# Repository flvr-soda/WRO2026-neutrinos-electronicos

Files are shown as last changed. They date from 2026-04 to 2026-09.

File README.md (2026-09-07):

# Neutrinos Electrónicos WRO 2026 - Terreneitor

## Table of Contents

- [Project Overview](#project-overview)
- [Team Introduction](#team-introduction)
- [The Robot: Terreneitor](#the-robot-terreneitor)
- [System Architecture](#system-architecture)
- [Hardware Specifications](#hardware-specifications)
- [Software Architecture](#software-architecture)
  - [Programming Languages](#programming-languages)
  - [Python Libraries](#python-libraries)
  - [Flowcharts](#flowcharts)
  - [Directory Structure](#directory-structure)
- [Algorithmic Logic](#algorithmic-logic)
  - [Finite State Machine (FSM)](#finite-state-machine-fsm)
  - [Computer Vision Processing](#computer-vision-processing)
  - [LiDAR-Based Parking](#lidar-based-parking)
  - [Serial Communication Protocol](#serial-communication-protocol)
- [Emergency Navigation System](#emergency-navigation-system)
- [Module Descriptions](#module-descriptions)
- [Installation and Setup](#installation-and-setup)
- [Configuration](#configuration)
- [Usage Instructions](#usage-instructions)
- [Component List](#component-list)
- [Robot Images](#robot-images)
- [Practice Videos](#practice-videos)
- [Development Milestones](#development-milestones)

---

## Project Overview

**Terreneitor** is an autonomous vehicle designed for the World Robot Olympiad (WRO) 2026 Future Engineers competition. The robot implements a hybrid computing architecture combining a **Raspberry Pi 4** as the high-level perception and decision unit and an **Arduino UNO** as the real-time hardware controller. This design guarantees sophisticated decision-making alongside deterministic, low-latency motor control.

**Key Design Principles:**
- **Hybrid Centralized Architecture:** Single Raspberry Pi 4 as master node with Arduino UNO as dedicated hardware controller to eliminate latency issues.
- **Isolated Control Loop:** PID-based motor control with encoder feedback running directly on the Arduino for immediate, smooth velocity regulation.
- **Configuration-Driven Logic:** Main competition parameters decoupled from source code via centralized `config.py` for rapid adjustments.
- **Modular Software Design:** Event-based Finite State Machine (FSM) on Raspberry Pi enabling independent development and validation of each race phase.
- **Dual-Track Reliability:** Complete primary vision-based navigation system alongside a lightweight, reactive **Safety System** (`code/safety_sys`).

---

## Team Introduction

<p align="center">
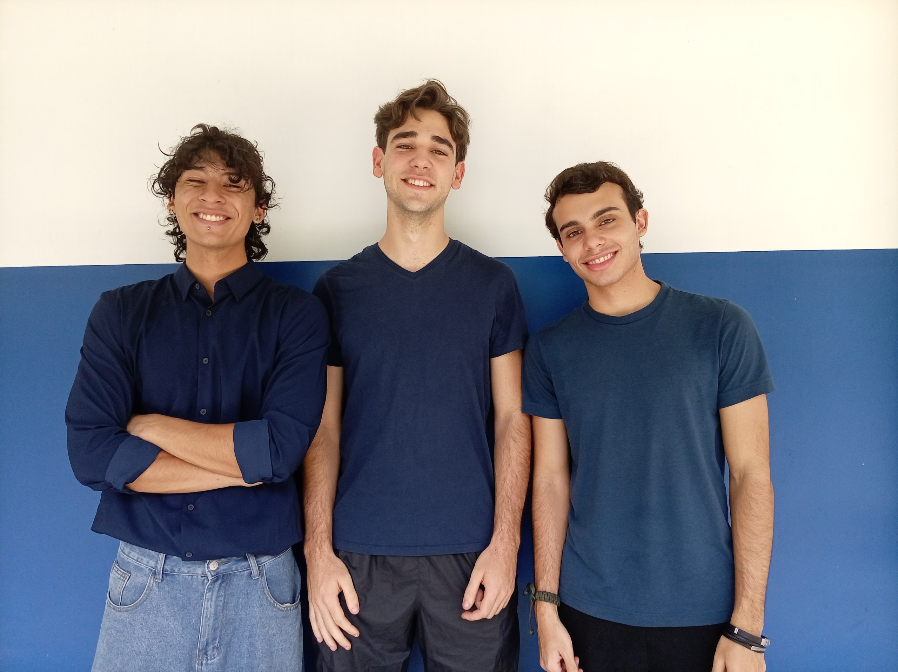
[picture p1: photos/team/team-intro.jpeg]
Team Photo
  
</p>

| Name | Role |
|---|---|
| **Ismael Armada** | Software Architecture & Control |
| **Sebastián Vera** | Mechanics & Chassis Design |
| **Andrés Lugo** | Electronics & Power Systems |
| **Milagro Rojas** | Coach |

- **Ismael Armada:** I am 20 years old, in my 4th semester of my Computer Science major. I learned about WRO thanks to a mutual friend I share with our team's coach. With this competition, I simply aim to challenge myself as a programmer by diving headfirst, for the very first time, into the development of a robotics project.
- **Sebastián Vera:** I am 18 years old and a Mechanical Engineering student, currently in my 3rd semester. I discovered WRO through my high school, as we were able to represent it during our senior year. I loved that experience, and it introduced me to this amazing world of robotics—how fun and challenging it really is! I hope to have the opportunity to represent both my team and my country in such an incredible competition.
- **Andrés Lugo:** I am 19 years old and an Electrical Engineering student, currently taking 2nd-semester courses in Mechanical Engineering. I got to know WRO by competing alongside Sebastián for the first time in our senior year of high school. I didn't have much knowledge back then, but it was my gateway into this world.

---

## The Robot: Terreneitor

Every project needs an identity, and ours was born out of a shared childhood memory. During one of our first team meetings, a conversation about remote-controlled cars revealed that every single member of our team had owned a "Terreneitor" toy car growing up. That shared memory inspired the name of our autonomous vehicle.

---

## System Architecture

The robot employs a dual-processor architecture optimized for high-level perception and real-time execution:

```
+-------------------------------------------------------------+
|                      RASPBERRY PI 4                         |
|  - Computer Vision (OpenCV / CSI Camera)                    |
|  - TF-Luna LiDAR Reader & SG90 Servo Control                |
|  - Finite State Machine (INICIO, NAVEGACION, ESTACIONAR)    |
|  - PID Steering & Speed Calculation                         |
|  - Rule Enforcement & Lap Counter                           |
+------------------------------+------------------------------+
                               | USB Serial (115200 baud)
                               | Command: V:<vel>;A:<ang>\n
                               | Telemetry: T:Z:<z>;A:<a>;U:<u>\n
+------------------------------v------------------------------+
|                       ARDUINO UNO                           |
|  - Non-blocking Command Parser                              |
|  - BTS7960 H-Bridge DC Motor PWM Drive                      |
|  - MG996R Steering Servo Control (40° - 140°)               |
|  - 100-line Quadrature Optical Encoder Interrupts           |
|  - HC-SR04 Rear Ultrasonic Distance Reader                  |
|  - MPU6050 6-DOF IMU Yaw Angle Integration                  |
+-------------------------------------------------------------+
```

---

## Hardware Specifications

### Main Processing Units
- **SBC:** Raspberry Pi 4 Model B (4GB RAM)
- **MCU:** Arduino UNO R3

### Power Architecture
- Independent high-capacity battery pack for traction motors
- Dedicated power supply for Raspberry Pi 4 and Arduino
- Voltage regulator: **XL4015** step-down buck converter (high-current stabilization)
- 5V active cooling fan for Raspberry Pi 4
- Two distinct switches: Main master power and physical start button (GPIO 23 / Pin 16)

### Sensors
- **Camera:** OV5647 5MP with 120° wide-angle field of view (CSI ribbon interface)
- **Front LiDAR:** TF-Luna ToF distance sensor mounted on SG90 panning servo
- **Rear Distance:** HC-SR04 ultrasonic sensor (connected to Arduino)
- **IMU:** MPU6050 6-DOF accelerometer and gyroscope (I2C)
- **Speed Sensor:** 100-line optical quadrature encoder on main transmission

### Actuators
- **Motor Driver:** BTS7960 43A High-Power H-Bridge
- **Traction Motor:** High-torque DC motor
- **Steering Servo:** MG996R metal-gear 180° servo motor
- **LiDAR Panning Servo:** SG90 micro servo

---

## Software Architecture

### Programming Languages
- **Python 3:** Raspberry Pi high-level logic, state machine, vision, and emergency modules.
- **C++:** Arduino firmware for real-time motor drive and sensor polling.

### Python Libraries
- `opencv-python`: Real-time color detection, ROI extraction, and morphological filtering.
- `pyserial`: Direct non-blocking serial communication between Pi and Arduino.
- `gpiozero`: Hardware interface for physical start button (WRO Rule 9.11) and servos.
- `numpy`: Numerical processing for vision masks and arrays.

### Flowcharts

#### 1. Raspberry Pi Perception & Decision-Making Flow

#### 2. Arduino UNO Real-Time Control Flow

#### 3. Integrated Dual-Node System & Inter-Board Communication

### Directory Structure

```
WRO2026-neutrinos-electronicos/
├── README.md                         # Main project documentation
├── LICENSE                           # Project license
├── .gitignore                        # Git exclusion rules
│
├── code/                             # Source code directory
│   ├── env/                          # Shared Python virtual environment
│   ├── requirements.txt               # Shared Python package dependencies
│   │
│   ├── scripts/                       # Execution and setup scripts
│   │   ├── start.sh                   # Parametrized launcher (robot|safety)
│   │   └── setup_services.sh          # Systemd service installation script
│   │
│   ├── services/                      # Systemd service files
│   │   ├── wro-robot.service          # Primary system service
│   │   └── wro-safety.service         # Alternative system service
│   │
│   ├── main_sys/                      # Primary Navigation System
│   │   ├── src/                        # Core modules
│   │   │   ├── main.py                 # Main entrypoint and FSM orchestrator
│   │   │   ├── config.py               # Direct configuration (no YAML)
│   │   │   ├── estados.py              # Consolidated FSM + states
│   │   │   ├── comms.py                # Arduino + LiDAR serial drivers
│   │   │   ├── vision.py               # Asynchronous HSV color detection
│   │   │   └── hardware.py            # Hardware interfaces for testing
│   │   └── tests/                      # Standalone diagnostic tests
│   │       ├── test_camara.py          # Camera headless & GUI diagnostic
│   │       ├── test_lidar.py           # LiDAR & servo angle test
│   │       ├── test_ultrasonico.py      # Ultrasonic reading test
│   │       └── test_completo.py       # Full sensor integration test
│   │
│   ├── safety_sys/                     # Alternative Navigation System
│   │   └── main.py                     # Dynamic mode reactive racer
│   │
│   └── arduino/                        # Arduino C++ Firmware
│       └── firmware_terreneitor.ino   # Monolithic firmware (motors, sensors, comms)
│
├── elec/                             # Electrical schematics and diagrams
├── mech/                             # 3D models and CAD files
├── photos/                           # Team and vehicle photographic documentation
└── videos/                           # Practice run videos
```

---

## Configuration

The system uses direct Python configuration in `main_sys/src/config.py` instead of YAML files. All competition parameters can be adjusted directly in the code:

- **Velocities:** Motor PWM values and target speeds for PID control
- **Servo Angles:** Steering angles for different navigation states
- **HSV Color Ranges:** Detection thresholds for red, green, and magenta
- **Competition Settings:** Lap limits, time limits, and challenge modes
- **Hardware Configuration:** GPIO pins and serial port settings
- **Vision Parameters:** Camera resolution and optical flow calibration
- **LiDAR Settings:** Servo angles and distance thresholds
- **Vehicle Dimensions:** Physical dimensions for parking calculations

The Safety System uses hardcoded constants in `safety_sys/main.py` for simplicity and reliability.

---

## Algorithmic Logic

### Finite State Machine (FSM)

The primary software on the Raspberry Pi uses an event-driven Finite State Machine (`code/raspberry_pi/estados/fsm.py`):

1. **`EstadoInicio` (Standby & Ready):**
   - Initializes sensor communication and hardware drivers.
   - Waits in standby mode until the physical start button (`GPIO 23`) is pressed (WRO Rule 9.11).
   - Transitions to `EstadoNavegacion`.

2. **`EstadoNavegacion` (Race Execution):**
   - Continuously receives non-blocking HSV vision detections (obstacle centroid, color).
   - Computes proportional steering angles to avoid pillars (Red $\rightarrow$ evade left, Green $\rightarrow$ evade right).
   - Tracks lap completion using accumulated encoder telemetry.
   - Enforces the 3-minute WRO round time limit.
   - Transitions to `EstadoEstacionar` (Obstacle Challenge) or `EstadoFin` (Open Challenge).

3. **`EstadoEstacionar` (Parallel Parking):**
   - Executes an automated 4-phase parking sequence using LiDAR gap detection:
     - **Phase 1 (Scan):** Sweeps LiDAR servo to identify the parking bay gap.
     - **Phase 2 (Approach):** Aligns the vehicle alongside the detected gap.
     - **Phase 3 (Reverse Entry):** Reverses into the space with calculated steering angle.
     - **Phase 4 (Straighten):** Centers vehicle between walls.
   - Transitions to `EstadoFin`.

4. **`EstadoFin` (Safe Shutdown):**
   - Immediately stops traction motor (`V:0`), centers steering (`A:90`), and safely releases all hardware connections.

---

## Safety System

Located in [`code/safety_sys/`](code/safety_sys), this system is a single-file, zero-overhead reactive alternative designed to guarantee full completion of 3 laps under high-stress competition conditions without relying on camera lighting calibration, OpenCV, or configuration files.

### Safety System Features:

**[`main.py`](code/safety_sys/main.py) — Dynamic Mode Reactive Racer:**
- Uses direct serial UART reads from the **TF-Luna LiDAR in a fixed forward position ($90^\circ$)** at 40 Hz.
- Cruises in straight lines (`V:65, A:90`).
- Camera always active for color detection (rojo/verde/morado)
- Upon detecting any color, permanently switches to obstacle avoidance mode
- When frontal obstacle is detected ($\le 50\text{ cm}$), performs reactive evasion
- Detects outer track corners ($\le 75\text{ cm}$) and completes 3 laps reliably.
- Automatically halts after exactly 12 corners (3 laps).

The script strictly follows the **WRO 9.11 Standby $\rightarrow$ Start Button** protocol.

---

## Installation and Setup

### Raspberry Pi Setup

1. **Clone repository:**
   ```bash
   cd /home/pi
   git clone https://github.com/flvr-soda/WRO2026-neutrinos-electronicos.git
   cd WRO2026-neutrinos-electronicos/code
   ```

2. **Create shared Python virtual environment & install dependencies:**
   ```bash
   python3 -m venv env
   source env/bin/activate
   pip install -r requirements.txt
   deactivate
   ```

3. **Install systemd services (automated):**
   ```bash
   cd scripts
   ./setup_services.sh setup           # Configure environment and permissions
   ./setup_services.sh install-robot  # Install primary system service
   ./setup_services.sh install-safety # Install alternative system service
   ```

4. **Install Arduino Firmware:**
   - Open `code/arduino/firmware_terreneitor.ino` in Arduino IDE.
   - Select Board `Arduino Uno` and target serial port.
   - Compile and upload.

---

## Usage Instructions

### Manual Execution

**Using the parametrized script:**
```bash
cd /home/pi/WRO2026-neutrinos-electronicos/code
source env/bin/activate

# Primary system
./scripts/start.sh robot

# Safety system
./scripts/start.sh safety
```

**Direct execution:**
```bash
cd /home/pi/WRO2026-neutrinos-electronicos/code
source env/bin/activate

# Primary system
cd main_sys
python3 src/main.py

# Safety system
cd safety_sys
python3 main.py
```

### Systemd Service Management

The `scripts/setup_services.sh` script provides automated service management:

```bash
cd /home/pi/WRO2026-neutrinos-electronicos/code/scripts

# Setup environment and permissions
./setup_services.sh setup

# Install and enable primary system
./setup_services.sh install-robot

# Switch to safety system
./setup_services.sh switch-safety

# Check service status
./setup_services.sh status robot
./setup_services.sh status safety

# View service logs
./setup_services.sh logs robot
./setup_services.sh logs safety
```

**Manual Service Management:**
```bash
# Enable primary system:
sudo systemctl enable wro-robot.service
sudo systemctl start wro-robot.service

# Enable safety system:
sudo systemctl enable wro-safety.service
sudo systemctl start wro-safety.service

# Check status:
sudo systemctl status wro-robot.service
sudo systemctl status wro-safety.service
```

---

## Component List

| Category | Component | Model / Specs | Purpose |
|:---|:---|:---|:---|
| **Processing** | Single Board Computer | Raspberry Pi 4 Model B (4GB) | Vision, FSM, Navigation, Decision Making |
| **Processing** | Microcontroller | Arduino UNO R3 | Real-time Motor Control, Telemetry |
| **Vision** | Camera Module | OV5647 5MP (120° FOV) | Pillar Color & Position Detection |
| **Distance** | LiDAR Sensor | Benewake TF-Luna (ToF UART) | Corner Detection, Wall Ranging & Parking |
| **Distance** | Ultrasonic Sensor | HC-SR04 | Rear Obstacle Measurement |
| **IMU** | Motion Sensor | MPU6050 6-DOF | Yaw Angle Tracking |
| **Actuator** | Motor Driver | BTS7960 43A H-Bridge | DC Traction Motor Drive |
| **Actuator** | Steering Servo | MG996R Metal Gear (180°) | Front Wheel Steering |
| **Actuator** | LiDAR Servo | SG90 Micro Servo (180°) | LiDAR Panning |
| **Regulation** | Buck Converter | XL4015 Step-Down Module | High-Current Clean Voltage Stabilization |

## License

This project is licensed under the MIT License - see the [LICENSE](LICENSE) file for details.

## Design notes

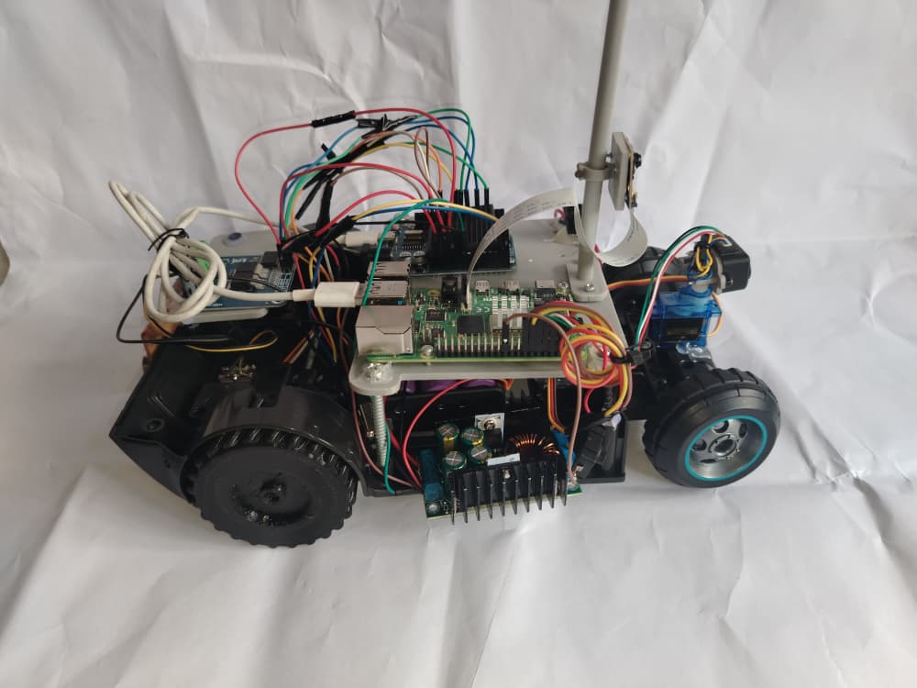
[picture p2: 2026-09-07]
photos/vehicle/izquierda_v3.jpeg

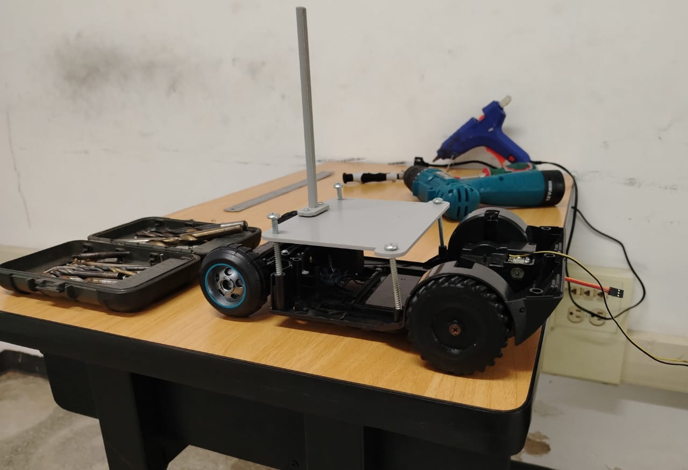
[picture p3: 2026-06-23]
photos/vehicle/terreneitor_v2.jpeg

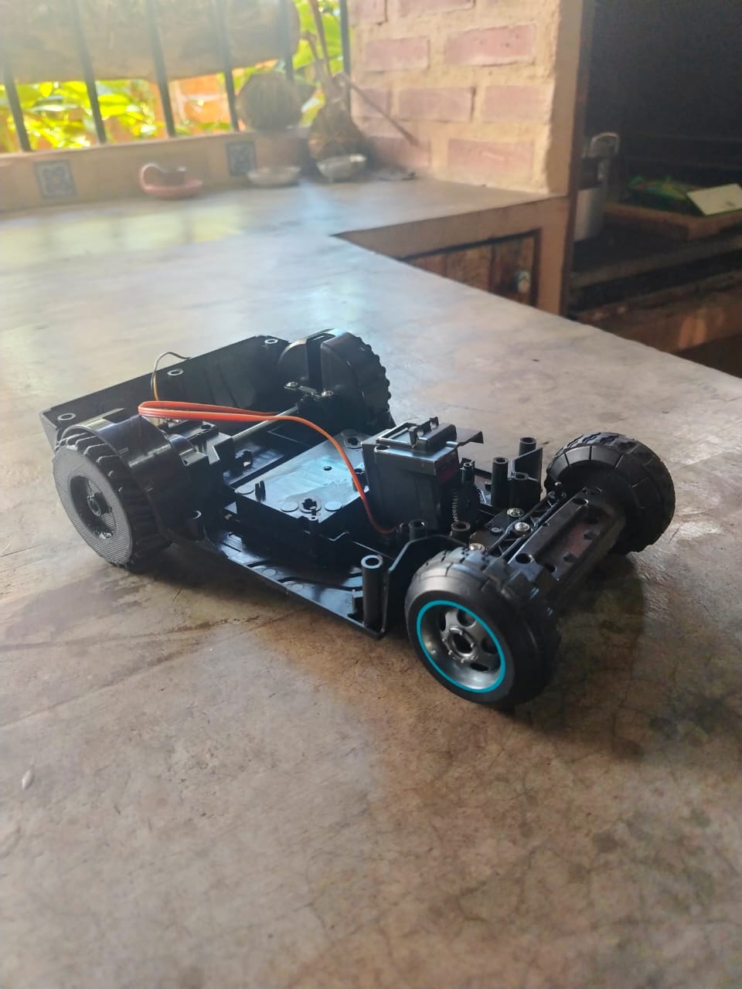
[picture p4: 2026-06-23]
photos/vehicle/terreneitor_v1.jpeg

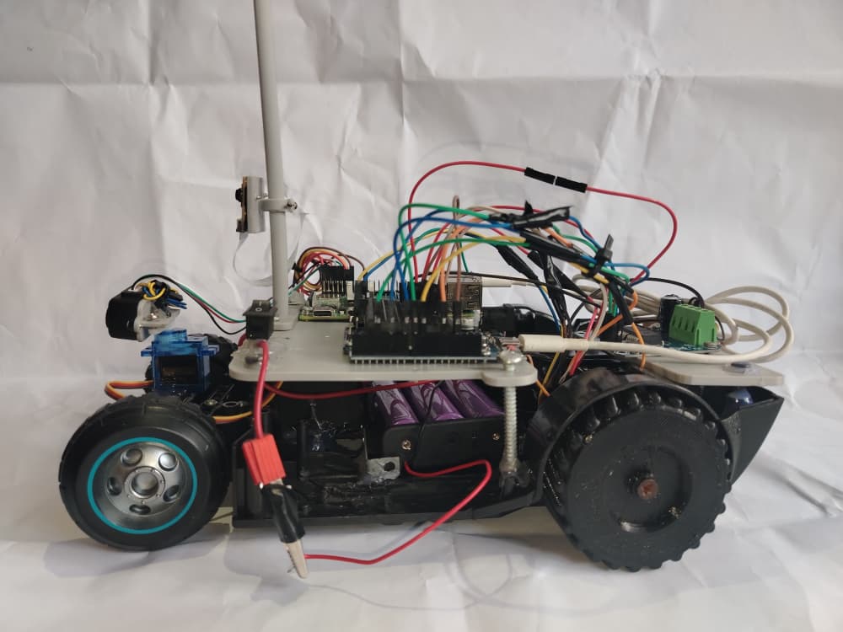
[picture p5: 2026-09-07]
photos/vehicle/derecha_v3.jpeg

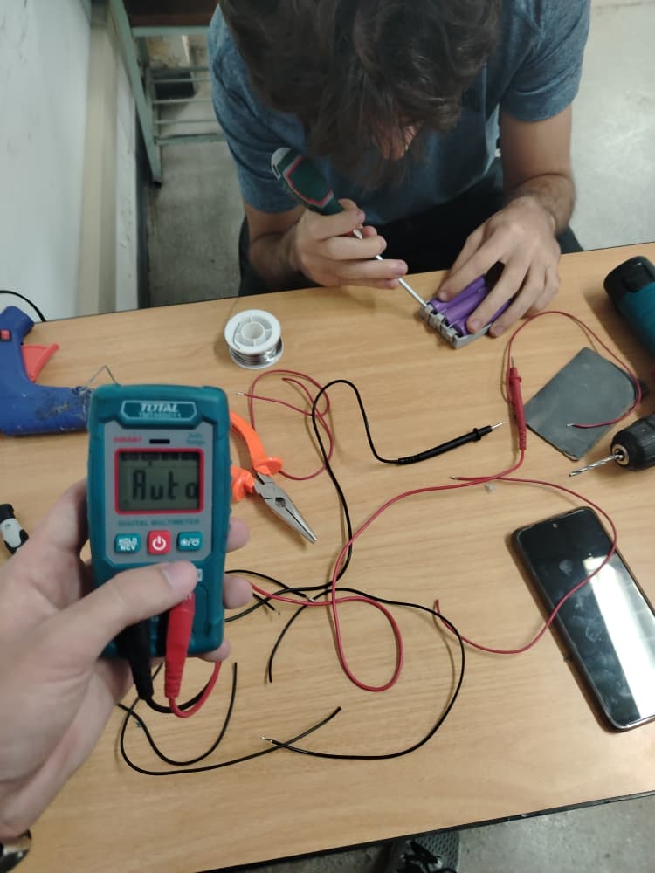
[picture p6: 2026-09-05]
photos/team/Medicion-voltaje-baterias.jpeg

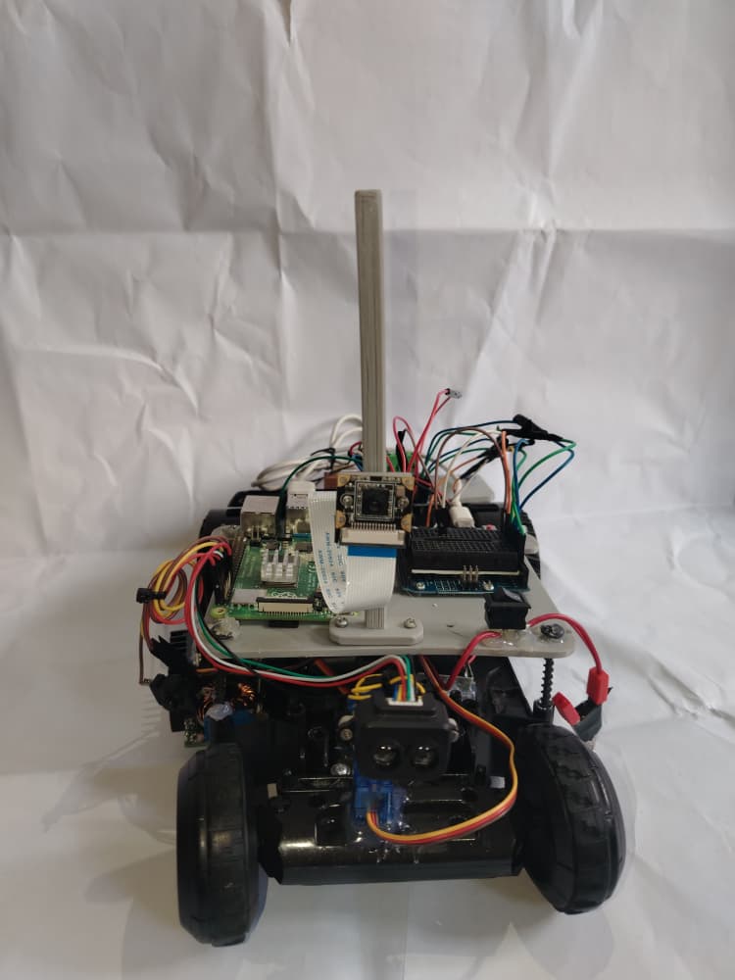
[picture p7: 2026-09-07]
photos/vehicle/frente_v3.jpeg

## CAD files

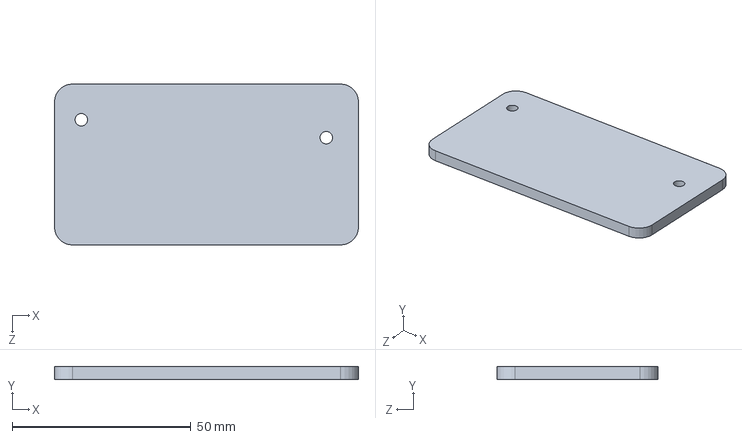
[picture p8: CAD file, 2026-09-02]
mech/3D/Base 2 WRO.SLDPRT
85.0 x 3.50 x 45.0 mm

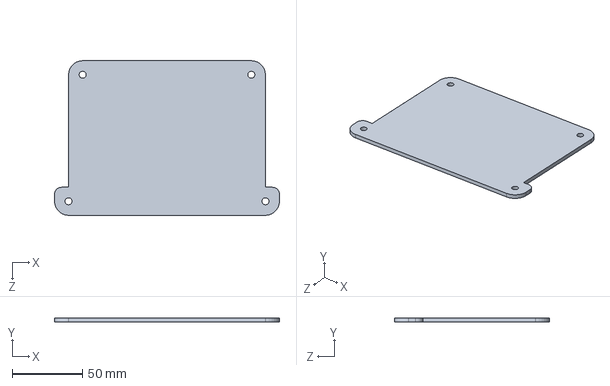
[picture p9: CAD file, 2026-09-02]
mech/3D/Base.SLDPRT
160.0 x 3.00 x 110.0 mm

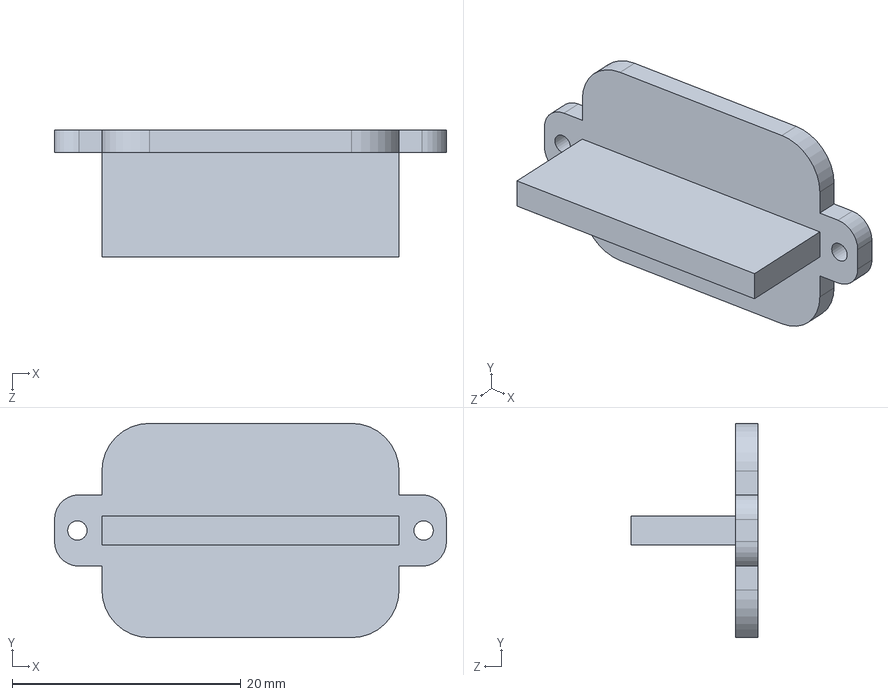
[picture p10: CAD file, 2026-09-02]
mech/3D/Base del Lidar WRO.SLDPRT
34.3 x 18.8 x 11.1 mm

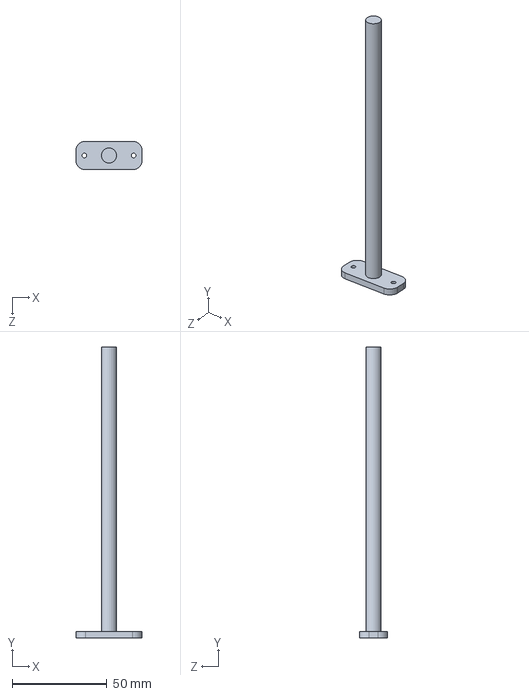
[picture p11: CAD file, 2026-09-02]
mech/3D/Base de la abrazadera WRO.SLDPRT
35.0 x 153.5 x 15.0 mm

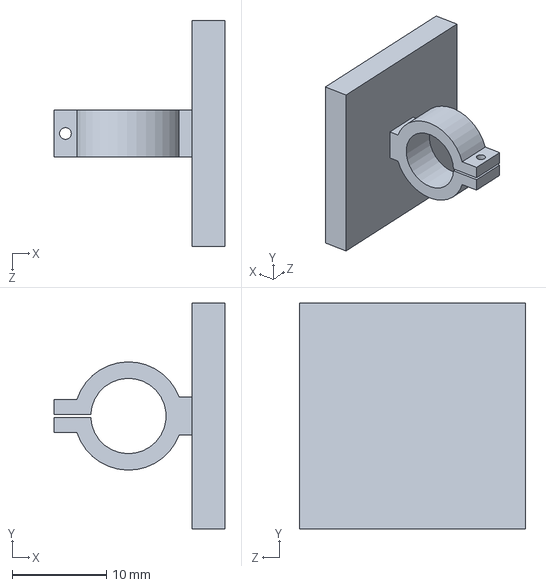
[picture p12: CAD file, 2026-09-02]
mech/3D/Abrazadera WRO.SLDPRT
18.2 x 24.0 x 24.0 mm

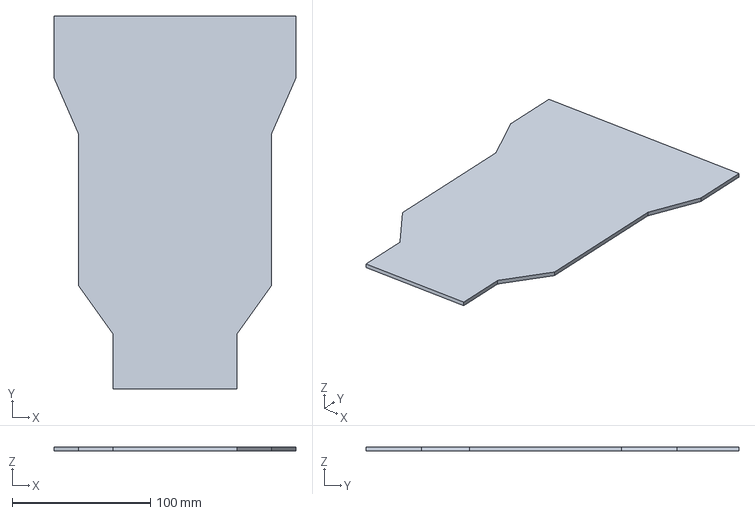
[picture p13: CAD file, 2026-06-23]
mech/3D/Chasis_Dimensiones_Preliminar.FCStd
175.0 x 270.0 x 3.00 mm

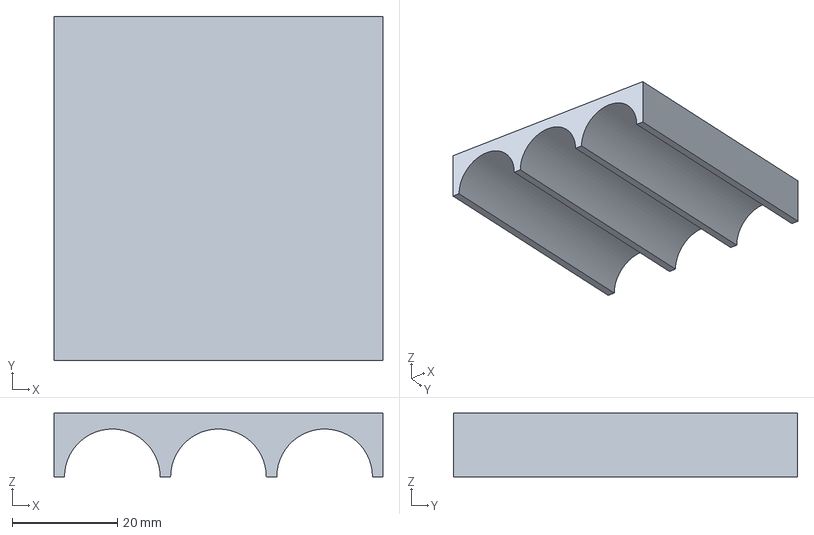
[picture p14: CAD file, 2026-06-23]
mech/3D/Chasis_Soporte_Baterias.FCStd
62.5 x 65.3 x 12.1 mm

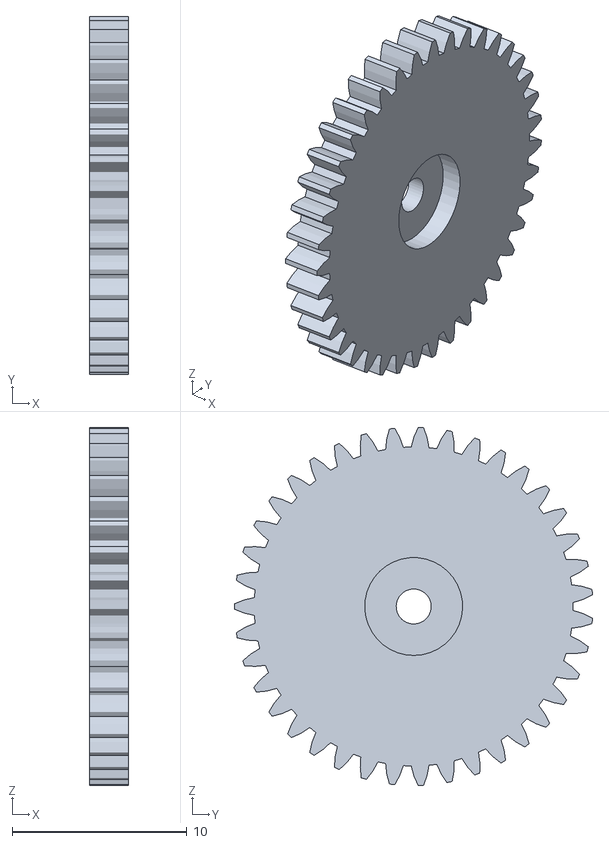
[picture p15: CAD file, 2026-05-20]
mech/3D/Engranaje.STL
2.25 x 20.5 x 20.5

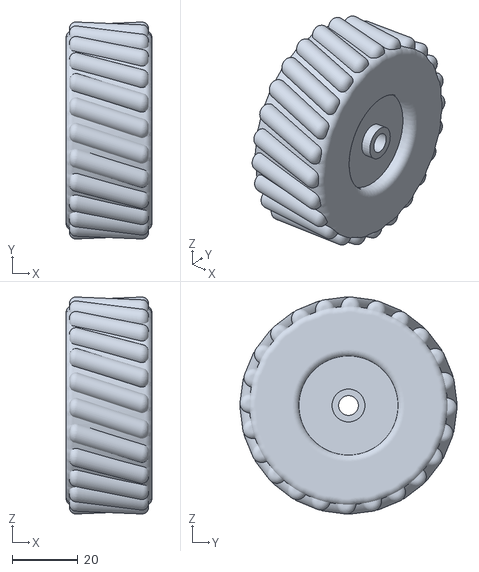
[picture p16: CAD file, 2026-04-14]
mech/3D/Rueda.STL
26.0 x 65.8 x 65.8

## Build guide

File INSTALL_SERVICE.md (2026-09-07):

# Instalación del Servicio Systemd para Inicio Automático

Este documento describe cómo instalar los servicios systemd para el sistema principal y el sistema alternativo.

## Servicios Disponibles

1. **wro-robot.service** - Sistema principal (main_sys/src/main.py)
2. **wro-safety.service** - Sistema alternativo (safety_sys/main.py)

**Nota:** Solo un servicio debe estar habilitado e iniciado a la vez.

## Instalación Automatizada (Recomendado)

El script `scripts/setup_services.sh` automatiza todo el proceso de instalación:

```bash
cd /home/pi/WRO2026-neutrinos-electronicos/code/scripts

# Configurar entorno virtual compartido y permisos
./setup_services.sh setup

# Instalar y habilitar sistema principal
./setup_services.sh install-robot

# Cambiar a sistema alternativo
./setup_services.sh switch-safety

# Verificar estado
./setup_services.sh status robot
./setup_services.sh status safety

# Ver logs
./setup_services.sh logs robot
./setup_services.sh logs safety
```

## Instalación Manual

### Requisitos Previos

1. **Crear entorno virtual compartido:**
   ```bash
   cd /home/pi/WRO2026-neutrinos-electronicos/code
   python3 -m venv env
   source env/bin/activate
   pip install -r requirements.txt
   deactivate
   ```

2. **Dar permisos de ejecución a los scripts:**
   ```bash
   chmod +x /home/pi/WRO2026-neutrinos-electronicos/code/scripts/start.sh
   chmod +x /home/pi/WRO2026-neutrinos-electronicos/code/scripts/setup_services.sh
   ```

### Para el Sistema Principal (wro-robot.service)

1. **Copiar el archivo de servicio al directorio de systemd:**
   ```bash
   sudo cp /home/pi/WRO2026-neutrinos-electronicos/code/services/wro-robot.service /etc/systemd/system/
   ```

2. **Recargar la configuración de systemd:**
   ```bash
   sudo systemctl daemon-reload
   ```

3. **Habilitar el servicio para que se inicie al arranque:**
   ```bash
   sudo systemctl enable wro-robot.service
   ```

4. **Iniciar el servicio manualmente (para probar):**
   ```bash
   sudo systemctl start wro-robot.service
   ```

5. **Verificar el estado del servicio:**
   ```bash
   sudo systemctl status wro-robot.service
   ```

### Para el Sistema Alternativo (wro-safety.service)

1. **Copiar el archivo de servicio al directorio de systemd:**
   ```bash
   sudo cp /home/pi/WRO2026-neutrinos-electronicos/code/services/wro-safety.service /etc/systemd/system/
   ```

2. **Recargar la configuración de systemd:**
   ```bash
   sudo systemctl daemon-reload
   ```

3. **Habilitar el servicio para que se inicie al arranque:**
   ```bash
   sudo systemctl enable wro-safety.service
   ```

4. **Iniciar el servicio manualmente (para probar):**
   ```bash
   sudo systemctl start wro-safety.service
   ```

5. **Verificar el estado del servicio:**
   ```bash
   sudo systemctl status wro-safety.service
   ```

### Cambiar entre Servicios

Para cambiar del sistema principal al alternativo (o viceversa):

1. **Detener y deshabilitar el servicio actual:**
   ```bash
   sudo systemctl stop wro-robot.service
   sudo systemctl disable wro-robot.service
   ```

2. **Habilitar e iniciar el nuevo servicio:**
   ```bash
   sudo systemctl enable wro-safety.service
   sudo systemctl start wro-safety.service
   ```

## Ejecución Manual

### Script Parametrizado

El script `scripts/start.sh` permite ejecutar manualmente cualquier sistema:

```bash
cd /home/pi/WRO2026-neutrinos-electronicos/code
source env/bin/activate

# Sistema principal
./scripts/start.sh robot

# Sistema alternativo
./scripts/start.sh safety
```

## Gestión del Servicio

### Ver logs del servicio:
```bash
# Sistema principal
sudo journalctl -u wro-robot.service -f

# Sistema alternativo
sudo journalctl -u wro-safety.service -f
```

### Detener el servicio:
```bash
# Sistema principal
sudo systemctl stop wro-robot.service

# Sistema alternativo
sudo systemctl stop wro-safety.service
```

### Reiniciar el servicio:
```bash
# Sistema principal
sudo systemctl restart wro-robot.service

# Sistema alternativo
sudo systemctl restart wro-safety.service
```

### Deshabilitar el inicio automático:
```bash
# Sistema principal
sudo systemctl disable wro-robot.service

# Sistema alternativo
sudo systemctl disable wro-safety.service
```

## Solución de Problemas

### El servicio no inicia:
1. Verificar que el entorno virtual compartido existe:
   ```bash
   ls -la /home/pi/WRO2026-neutrinos-electronicos/code/env/
   ```

2. Verificar que el script start.sh tiene permisos de ejecución:
   ```bash
   ls -la /home/pi/WRO2026-neutrinos-electronicos/code/scripts/start.sh
   ```

3. Revisar los logs para errores:
   ```bash
   sudo journalctl -u wro-robot.service -n 50
   sudo journalctl -u wro-safety.service -n 50
   ```

### El servicio se reinicia constantemente:
- Esto puede indicar que el programa principal está fallando. Revisa los logs para ver el error específico.

## Notas Importantes

- **Script parametrizado:** `scripts/start.sh` usa parámetros `robot` o `safety` para evitar duplicación
- **Entorno virtual compartido:** Ambos sistemas usan el mismo entorno virtual en `code/env/` para optimizar espacio
- **Configuración directa:** El sistema principal usa `config.py` en lugar de archivos YAML para simplicidad
- **Restart automático:** El servicio se reiniciará automáticamente si el programa falla (configuración `Restart=always`)
- **Delay de reinicio:** El servicio se reiniciará 10 segundos después de fallar (configuración `RestartSec=10`)
- **Logs:** Los logs se guardan en el journal de systemd y pueden verse con `journalctl`
- **Usuario:** El servicio se ejecuta como usuario `pi` por seguridad

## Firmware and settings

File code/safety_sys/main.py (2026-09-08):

#!/usr/bin/env python3
"""
SISTEMA DE SEGURIDAD WRO - Sensor Ultrasónico
Objetivo: Navegación autónoma con autodetección de sentido y esquiva de pilares.

Funcionalidades:
- Autodetección de sentido de giro usando servo SG90 + ultrasónico frontal
- Conteo de esquinas por detección de muro a 85cm
- Ángulo de giro máximo posible
- Velocidad 60% en rectas, 35% en giros
- Cámara activa para detección de pilares rojo/verde
- Esquiva: verde → izquierda, rojo → derecha
- Ultrasónico trasero para retroceso seguro (5cm)
"""

import time
import serial
import logging
import os
import sys
import glob

# Configurar pin factory RPi.GPIO
os.environ['GPIOZERO_PIN_FACTORY'] = 'rpigpio'

try:
    from gpiozero import Button, AngularServo, DigitalOutputDevice, InputDevice
except ImportError:
    Button = None
    AngularServo = None
    DigitalOutputDevice = None
    InputDevice = None

try:
    import cv2
    import numpy as np
    VISION_DISPONIBLE = True
except ImportError:
    cv2 = None
    np = None
    VISION_DISPONIBLE = False

# ==============================================================================
# CONFIGURACIÓN
# ==============================================================================

# Pines GPIO
PIN_BOTON_INICIO = 17
PIN_SERVO_SCANNER = 18
PIN_ULTRASONICO_FRONTAL_TRIGGER = 23
PIN_ULTRASONICO_FRONTAL_ECHO = 24
PIN_ULTRASONICO_TRASERO_TRIGGER = 5
PIN_ULTRASONICO_TRASERO_ECHO = 6

# Parámetros de navegación
VUELTAS_OBJETIVO = 3
ESQUINAS_POR_VUELTA = 4
TOTAL_ESQUINAS = VUELTAS_OBJETIVO * ESQUINAS_POR_VUELTA

# Velocidades (0-100)
VELOCIDAD_RECTA = 60
VELOCIDAD_GIRO = 35

# Ángulos servo dirección Arduino
ANGULO_RECTO = 90
ANGULO_GIRO_MAXIMO_DERECHA = 0
ANGULO_GIRO_MAXIMO_IZQUIERDA = 180

# Ángulos servo escaneo
ANGULO_SERVO_CENTRO = 90
ANGULO_SERVO_DERECHA = 40
ANGULO_SERVO_IZQUIERDA = 140

# Umbrales distancia (cm)
DISTANCIA_ESQUINA_CM = 85.0
DISTANCIA_RETROCESO_CM = 5.0

# Tiempos
DURACION_GIRO_SEG = 1.5
COOLDOWN_ESQUINA_SEG = 1.5
TIEMPO_PANEO_SEG = 0.4

# Colores HSV (rojo y verde)
RANGOS_COLOR = {
    'rojo': [(np.array([0, 100, 100]), np.array([10, 255, 255])) if VISION_DISPONIBLE else None,
             (np.array([170, 100, 100]), np.array([180, 255, 255])) if VISION_DISPONIBLE else None],
    'verde': [(np.array([40, 50, 50]), np.array([85, 255, 255])) if VISION_DISPONIBLE else None]
}

# Arduino
BAUD_ARDUINO = 115200

# Logging
logging.basicConfig(level=logging.INFO, format='%(asctime)s [%(levelname)s] %(message)s')
logger = logging.getLogger("SAFETY_ULTRASONICO")

# ==============================================================================
# DRIVER SERVO SCANNER
# ==============================================================================

class ServoScanner:
    """Controla servo SG90 para escaneo lateral con ultrasónico."""
    def __init__(self, pin=PIN_SERVO_SCANNER, angulo_centro=ANGULO_SERVO_CENTRO):
        self.pin = pin
        self.angulo_centro = angulo_centro
        self.servo = None
        self._inicializar()

    def _inicializar(self):
        if AngularServo is None:
            logger.warning("[Servo Scanner] gpiozero no disponible")
            return
        try:
            self.servo = AngularServo(
                self.pin,
                min_angle=0,
                max_angle=180,
                min_pulse_width=0.0005,
                max_pulse_width=0.0025,
                initial_angle=self.angulo_centro
            )
            logger.info(f"[Servo Scanner] ✓ Inicializado en GPIO {self.pin}")
        except Exception as e:
            logger.warning(f"[Servo Scanner] Error: {e}")
            self.servo = None

    def centrar(self):
        self.mover(self.angulo_centro)

    def mover(self, angulo):
        if self.servo:
            try:
                self.servo.angle = max(0.0, min(180.0, float(angulo)))
            except Exception as e:
                logger.debug(f"[Servo Scanner] Error moviendo: {e}")

    def cerrar(self):
        if self.servo:
            try:
                self.centrar()
                time.sleep(0.05)
                self.servo.close()
            except Exception:
                pass
            self.servo = None

# ==============================================================================
# DRIVER SENSOR ULTRASÓNICO
# ==============================================================================

class UltrasonicSensor:
    """Driver para sensor ultrasónico HC-SR04."""
    def __init__(self, trigger_pin, echo_pin, nombre="Ultrasonido"):
        self.trigger_pin = trigger_pin
        self.echo_pin = echo_pin
        self.nombre = nombre
        self.trigger = None
        self.echo = None
        self.ultima_distancia = 300.0
        self._inicializar()

    def _inicializar(self):
        if DigitalOutputDevice is None or InputDevice is None:
            logger.warning(f"[{self.nombre}] gpiozero no disponible")
            return
        try:
            self.trigger = DigitalOutputDevice(self.trigger_pin)
            self.echo = InputDevice(self.echo_pin)
            logger.info(f"[{self.nombre}] ✓ Inicializado TRIGGER={self.trigger_pin}, ECHO={self.echo_pin}")
        except Exception as e:
            logger.warning(f"[{self.nombre}] Error: {e}")
            self.trigger = None
            self.echo = None

    def leer_distancia_cm(self):
        if not self.trigger or not self.echo:
            return -1.0

        try:
            self.trigger.off()
            time.sleep(0.00001)
            self.trigger.on()
            time.sleep(0.00001)
            self.trigger.off()

            start_time = time.monotonic()
            timeout = start_time + 0.04
            
            while not self.echo.is_active and time.monotonic() < timeout:
                pass
            
            pulse_start = time.monotonic()
            
            while self.echo.is_active and time.monotonic() < timeout:
                pass
            
            pulse_end = time.monotonic()
            
            pulse_duration = pulse_end - pulse_start
            distancia = (pulse_duration * 34300) / 2
            
            if 2.0 <= distancia <= 400.0:
                self.ultima_distancia = distancia
                return distancia
            
        except Exception as e:
            logger.debug(f"[{self.nombre}] Error: {e}")

        return -1.0

    def medir_promedio(self, muestras=3, pausa=0.02):
        lecturas = []
        for _ in range(muestras):
            d = self.leer_distancia_cm()
            if d > 0:
                lecturas.append(d)
            time.sleep(pausa)
        return sum(lecturas)/len(lecturas) if lecturas else -1.0

    def cerrar(self):
        if self.trigger:
            try:
                self.trigger.close()
            except Exception:
                pass
        if self.echo:
            try:
                self.echo.close()
            except Exception:
                pass

# ==============================================================================
# DRIVER ARDUINO
# ==============================================================================

class ArduinoDriver:
    """Control de motores vía Arduino."""
    def __init__(self, baudrate=BAUD_ARDUINO):
        self.baudrate = baudrate
        self.conn = None
        self.port = self._buscar_puerto()
        self.conectar()

    def _buscar_puerto(self):
        puertos = glob.glob('/dev/ttyUSB*') + glob.glob('/dev/ttyACM*')
        if puertos:
            return puertos[0]
        return '/dev/ttyUSB0'

    def conectar(self):
        try:
            self.conn = serial.Serial(self.port, self.baudrate, timeout=0.01)
            logger.info(f"[Arduino] ✓ Conectado en {self.port}")
        except Exception as e:
            logger.warning(f"[Arduino] Error al conectar: {e}")
            self.conn = None

    def enviar(self, velocidad, angulo):
        if self.conn and self.conn.is_open:
            try:
                comando = f"{velocidad},{angulo}\n"
                logger.info(f"[Arduino] Enviando: {comando.strip()}")
                self.conn.write(comando.encode())
            except Exception as e:
                logger.warning(f"[Arduino] Error enviando: {e}")

    def frenar(self):
        self.enviar(0, ANGULO_RECTO)

    def cerrar(self):
        if self.conn and self.conn.is_open:
            try:
                self.frenar()
                time.sleep(0.1)
                self.conn.close()
            except Exception:
                pass

# ==============================================================================
# DETECTOR DE COLOR
# ==============================================================================

class ColorDetector:
    """Detección de pilares rojo/verde con OpenCV."""
    def __init__(self, camara_index=0):
        self.camara_index = camara_index
        self.cap = None
        self.disponible = False
        self._inicializar()

    def _inicializar(self):
        if not VISION_DISPONIBLE:
            logger.warning("[Visión] OpenCV no disponible")
            return
        try:
            self.cap = cv2.VideoCapture(self.camara_index)
            if self.cap.isOpened():
                self.disponible = True
                logger.info("[Visión] ✓ Cámara inicializada")
            else:
                logger.warning("[Visión] No se pudo abrir cámara")
        except Exception as e:
            logger.warning(f"[Visión] Error: {e}")

    def detectar_color(self):
        if not self.disponible or self.cap is None:
            return None

        try:
            ret, frame = self.cap.read()
            if not ret:
                return None

            hsv = cv2.cvtColor(frame, cv2.COLOR_BGR2HSV)
            
            # Detectar rojo
            for lower, upper in RANGOS_COLOR['rojo']:
                if lower is not None and upper is not None:
                    mask = cv2.inRange(hsv, lower, upper)
                    if cv2.countNonZero(mask) > 500:
                        return 'rojo'
            
            # Detectar verde
            for lower, upper in RANGOS_COLOR['verde']:
                if lower is not None and upper is not None:
                    mask = cv2.inRange(hsv, lower, upper)
                    if cv2.countNonZero(mask) > 500:
                        return 'verde'
            
        except Exception as e:
            logger.debug(f"[Visión] Error: {e}")

        return None

    def cerrar(self):
        if self.cap:
            try:
                self.cap.release()
            except Exception:
                pass

# ==============================================================================
# SISTEMA PRINCIPAL
# ==============================================================================

class SafetyUltrasonico:
    def __init__(self):
        logger.info("=== Inicializando Sistema Safety Ultrasónico ===")
        self.servo_scanner = ServoScanner()
        self.ultrasonico_frontal = UltrasonicSensor(PIN_ULTRASONICO_FRONTAL_TRIGGER, PIN_ULTRASONICO_FRONTAL_ECHO, "Ultrasonido Frontal")
        self.ultrasonico_trasero = UltrasonicSensor(PIN_ULTRASONICO_TRASERO_TRIGGER, PIN_ULTRASONICO_TRASERO_ECHO, "Ultrasonico Trasero")
        self.arduino = ArduinoDriver()
        self.vision = ColorDetector()
        self.boton = None

        if Button is not None:
            try:
                self.boton = Button(PIN_BOTON_INICIO, pull_up=True)
                logger.info(f"[Botón] ✓ Configurado en GPIO {PIN_BOTON_INICIO}")
            except Exception as e:
                logger.warning(f"[Botón] Error: {e}")

        # Estado
        self.esquinas_completadas = 0
        self.sentido_giro = None  # 'derecha' o 'izquierda'
        self.angulo_giro = None
        self.en_giro = False
        self.tiempo_ultima_esquina = 0.0
        self.en_esquiva = False
        self.color_detectado = None
        self.boton_estado_anterior = None  # Para detectar cambios durante carrera

    def autodetectar_sentido_giro(self):
        """Paneo lateral para detectar dirección de la pista."""
        logger.info("[AUTODETECCIÓN] Escaneando dirección de la pista...")
        
        # Medir derecha
        self.servo_scanner.mover(ANGULO_SERVO_DERECHA)
        time.sleep(TIEMPO_PANEO_SEG)
        dist_der = self.ultrasonico_frontal.medir_promedio(muestras=3)
        
        # Medir izquierda
        self.servo_scanner.mover(ANGULO_SERVO_IZQUIERDA)
        time.sleep(TIEMPO_PANEO_SEG)
        dist_izq = self.ultrasonico_frontal.medir_promedio(muestras=3)
        
        # Volver al centro
        self.servo_scanner.centrar()
        
        logger.info(f"[AUTODETECCIÓN] Derecha: {dist_der:.0f}cm | Izquierda: {dist_izq:.0f}cm")
        
        if dist_der >= dist_izq:
            self.sentido_giro = 'derecha'
            self.angulo_giro = ANGULO_GIRO_MAXIMO_DERECHA
        else:
            self.sentido_giro = 'izquierda'
            self.angulo_giro = ANGULO_GIRO_MAXIMO_IZQUIERDA
        
        logger.info(f"[AUTODETECCIÓN] ✓ Sentido: {self.sentido_giro.upper()} (Ángulo: {self.angulo_giro}°)")
        return self.sentido_giro

    def esquiva_pilar(self, color):
        """Esquiva pilar según color."""
        logger.info(f"[ESQUIVA] Pilar {color} detectado")
        self.en_esquiva = True
        
        if color == 'verde':
            # Esquivar hacia la izquierda
            logger.info("[ESQUIVA] Girando a la izquierda...")
            self.arduino.enviar(VELOCIDAD_GIRO, ANGULO_GIRO_MAXIMO_IZQUIERDA)
            time.sleep(0.8)
            self.arduino.enviar(VELOCIDAD_RECTA, ANGULO_RECTO)
        elif color == 'rojo':
            # Esquivar hacia la derecha
            logger.info("[ESQUIVA] Girando a la derecha...")
            self.arduino.enviar(VELOCIDAD_GIRO, ANGULO_GIRO_MAXIMO_DERECHA)
            time.sleep(0.8)
            self.arduino.enviar(VELOCIDAD_RECTA, ANGULO_RECTO)
        
        self.en_esquiva = False

    def retroceso_seguro(self):
        """Retrocede si ultrasónico trasero detecta obstáculo a 5cm."""
        dist_trasera = self.ultrasonico_trasero.leer_distancia_cm()
        if dist_trasera > 0 and dist_trasera < DISTANCIA_RETROCESO_CM:
            logger.warning(f"[RETROCESO] Obstáculo trasero a {dist_trasera:.0f}cm")
            self.arduino.enviar(-30, ANGULO_RECTO)  # Velocidad negativa para retroceder
            time.sleep(0.5)
            self.arduino.frenar()
            return True
        return False

    def esperar_inicio(self):
        """Espera activación del botón."""
        logger.info("==================================================")
        logger.info("[STANDBY] Esperando a que se RESIONE el botón...")
        
        if self.boton is not None:
            # Espera bloqueante hasta que se presione físicamente
            self.boton.wait_for_press()
            logger.info("¡Botón presionado! Suelte el botón para iniciar...")
            
            # Espera a que el usuario levante el dedo para no arrastrar el estado a la carrera
            self.boton.wait_for_release()
            
            logger.info("Arrancando en 0.5s...")
            time.sleep(0.5)
            
            # Inicializamos el estado anterior como "No presionado" (False)
            self.boton_estado_anterior = False 
            return True
        else:
            logger.info("Botón no disponible. Presione ENTER...")
            input()
            return True

    def run(self):
        """Bucle principal de navegación."""
        if not self.esperar_inicio():
            return

        logger.info("=== INICIANDO NAVEGACIÓN ===")
        logger.info(f"Meta: {TOTAL_ESQUINAS} esquinas ({VUELTAS_OBJETIVO} vueltas)")
        
        self.servo_scanner.centrar()
        self.arduino.enviar(VELOCIDAD_RECTA, ANGULO_RECTO)
        
        primera_esquina = True
        
        try:
            while self.esquinas_completadas < TOTAL_ESQUINAS:
                ahora = time.monotonic()
                
                # Verificar si el botón se PRESIONA nuevamente (pasa de False a True)
                if self.boton is not None:
                    boton_estado_actual = self.boton.is_pressed
                    
                    # Solo actúa si se presiona el botón (True) y antes no lo estaba (False)
                    if boton_estado_actual == True and self.boton_estado_anterior == False:
                        logger.info("[STOP] Botón presionado - Deteniendo carrera")
                        self.arduino.frenar()
                        
                        # Esperar a que el usuario suelte el botón
                        self.boton.wait_for_release()
                        
                        logger.info("[REINICIO] Reiniciando carrera...")
                        time.sleep(1.0)
                        
                        # Reiniciar estado
                        self.esquinas_completadas = 0
                        self.sentido_giro = None
                        self.angulo_giro = None
                        self.en_giro = False
                        self.tiempo_ultima_esquina = 0.0
                        self.en_esquiva = False
                        self.color_detectado = None
                        self.boton_estado_anterior = False # Dejar limpio para el siguiente ciclo
                        primera_esquina = True
                        
                        logger.info("[REINICIO] Carrera reiniciada. Continuando...")
                        self.servo_scanner.centrar()
                        self.arduino.enviar(VELOCIDAD_RECTA, ANGULO_RECTO)
                        continue
                        
                    self.boton_estado_anterior = boton_estado_actual
                
                # Leer distancia frontal
                dist_frontal = self.ultrasonico_frontal.leer_distancia_cm()
                
                # Verificar retroceso seguro
                if self.retroceso_seguro():
                    continue
                
                # Detectar color
                color = self.vision.detectar_color()
                if color and color != self.color_detectado:
                    self.color_detectado = color
                    self.esquiva_pilar(color)
                    continue
                
                # Lógica de esquinas
                tiempo_desde_esquina = ahora - self.tiempo_ultima_esquina
                
                if not self.en_giro and not self.en_esquiva:
                    if dist_frontal > 0 and dist_frontal <= DISTANCIA_ESQUINA_CM and tiempo_desde_esquina >= COOLDOWN_ESQUINA_SEG:
                        logger.info(f"[ESQUINA] Muro detectado a {dist_frontal:.0f}cm")
                        
                        if primera_esquina:
                            # Autodetectar sentido en primera esquina
                            self.autodetectar_sentido_giro()
                            primera_esquina = False
                        
                        self.en_giro = True
                        self.tiempo_inicio_giro = ahora
                        
                        # Ejecutar giro
                        logger.info(f"[GIRO] Girando {self.sentido_giro} a {self.angulo_giro}°")
                        self.arduino.enviar(VELOCIDAD_GIRO, self.angulo_giro)
                
                # Finalizar giro
                if self.en_giro:
                    tiempo_en_giro = ahora - self.tiempo_inicio_giro
                    if tiempo_en_giro >= DURACION_GIRO_SEG:
                        self.en_giro = False
                        self.esquinas_completadas += 1
                        self.tiempo_ultima_esquina = ahora
                        logger.info(f"[ESQUINA] ✓ Completada ({self.esquinas_completadas}/{TOTAL_ESQUINAS})")
                        
                        # Volver a recta
                        self.arduino.enviar(VELOCIDAD_RECTA, ANGULO_RECTO)
                
                time.sleep(0.025)  # ~40Hz
            
            logger.info("=== CARRERA COMPLETADA ===")
            self.arduino.frenar()
            
        except KeyboardInterrupt:
            logger.info("Interrumpido por usuario")
        finally:
            self.limpiar()

    def limpiar(self):
        logger.info("Cerrando subsistemas...")
        self.arduino.cerrar()
        self.servo_scanner.cerrar()
        self.ultrasonico_frontal.cerrar()
        self.ultrasonico_trasero.cerrar()
        self.vision.cerrar()
        logger.info("Sistema finalizado")

if __name__ == "__main__":
    sistema = SafetyUltrasonico()
    sistema.run()

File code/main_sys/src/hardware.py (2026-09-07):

"""
Hardware Abstraction Layer for Testing
Simplified implementations for development/testing without real hardware
"""

import numpy as np
import logging
import time
from typing import Optional

# Intentar importar librerías reales de Raspberry Pi
try:
    import RPi.GPIO as GPIO
    GPIO_AVAILABLE = True
except ImportError:
    GPIO_AVAILABLE = False
    GPIO = None


class MockCamera:
    """Cámara simulada para desarrollo/pruebas sin hardware"""
    
    def __init__(self):
        self.width = 640
        self.height = 480
        self._connected = False
        self._frame_count = 0
        logging.info("Using MockCamera (simulated hardware)")
        
    def setup(self, width: int = 640, height: int = 480, format: str = 'RGB888') -> bool:
        """Inicializa cámara simulada"""
        self.width = width
        self.height = height
        self._connected = True
        logging.info(f"MockCamera initialized: {width}x{height}, format={format}")
        return True
    
    def capture_frame(self) -> Optional[np.ndarray]:
        """Captura un frame simulado (patrón de gradiente)"""
        if not self._connected:
            return None
            
        self._frame_count += 1
        
        # Crear un patrón de gradiente que cambia con el tiempo
        frame = np.zeros((self.height, self.width, 3), dtype=np.uint8)
        
        # Crear un gradiente de color que cambia con el tiempo
        offset = (self._frame_count * 2) % 256
        for y in range(self.height):
            for x in range(self.width):
                frame[y, x, 0] = (x + offset) % 256  # Red
                frame[y, x, 1] = (y + offset) % 256  # Green
                frame[y, x, 2] = ((x + y) // 2 + offset) % 256  # Blue
        
        return frame
    
    def start(self) -> None:
        """Inicia cámara simulada (sin operación)"""
        self._connected = True
        logging.info("MockCamera started")
    
    def stop(self) -> None:
        """Detiene cámara simulada"""
        self._connected = False
        logging.info("MockCamera stopped")
    
    def is_connected(self) -> bool:
        """Verifica si la cámara simulada está conectada"""
        return self._connected


class MockServo:
    """Servo simulado para desarrollo/pruebas sin hardware"""

    def __init__(self):
        self.pin = None
        self.frequency = 50
        self._initialized = False
        self._current_angle = 90
        logging.info("Using MockServo (simulated hardware)")

    def setup(self, pin: int, frequency: int = 50) -> bool:
        """Inicializa servo simulado"""
        self.pin = pin
        self.frequency = frequency
        self._initialized = True
        self._current_angle = 90
        logging.info(f"MockServo initialized on pin {pin} at {frequency}Hz")
        return True

    def set_angle(self, angle: float) -> None:
        """Establece ángulo simulado del servo (0-180 grados)"""
        if not self._initialized:
            return

        # Limitar ángulo al rango válido
        angle = max(0, min(180, angle))
        self._current_angle = angle
        logging.debug(f"MockServo: Angle set to {angle} degrees")
        # Simular retraso de movimiento del servo
        time.sleep(0.01)

    def stop(self) -> None:
        """Detiene señal PWM del servo simulado (sin operación)"""
        logging.debug("MockServo: PWM stopped")

    def cleanup(self) -> None:
        """Limpia recursos del servo simulado"""
        self._initialized = False
        logging.info("MockServo cleaned up")

    def is_available(self) -> bool:
        """Servo simulado siempre está disponible"""
        return True
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

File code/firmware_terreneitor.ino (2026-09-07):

#include <Servo.h>
#include <Wire.h>

// ============================================================
// DEFINICIÓN DE PINES
// ============================================================
// Servo de Dirección
const int PIN_SERVO = 9;

// Puente H BTS7960
const int PIN_RPWM = 5; // PWM Derecha (Avanzar)
const int PIN_LPWM = 3; // PWM Izquierda (Retroceder)
const int PIN_R_EN = 7; // Enable Derecha
const int PIN_L_EN = 8; // Enable Izquierda 

// HC-SR04 Trasero
const int PIN_TRIG_TRASERO = 12;
const int PIN_ECHO_TRASERO = 13;

// Constantes de calibración del giroscopio
const int GYRO_BIAS_MUESTRAS = 100;  // Reducido para no bloquear mucho tiempo
const float GYRO_DEADBAND_DPS = 1.5f;

// ============================================================
// VARIABLES GLOBALES
// ============================================================
int velocidadActual = 0;
int anguloActual = 90;
String inputString = "";
bool stringComplete = false;

// Variables de sensores
float mpu_z_acumulado = 0.0;
float distancia_trasera_cm = -1.0;
static unsigned long ultimaMedicionUs = 0;
const int MPU_ADDR = 0x68;
static float gyro_z_bias = 0.0f;
static unsigned int ciclo_sensor = 0;
static float historico_distancias[5] = {-1.0, -1.0, -1.0, -1.0, -1.0};
static int idx_historico = 0;
const float DISTANCIA_EMERGENCIA_CM = 5.0;

// Variables de control
Servo servoDireccion;
static unsigned long ultimoSensoresMs = 0;
static unsigned long ultimoTelemetriaMs = 0;
const unsigned long SENSORES_INTERVALO_MS = 10;
const unsigned long TELEMETRIA_INTERVALO_MS = 100;

// ============================================================
// INICIALIZACIÓN
// ============================================================
void setup() {
  initComunicacion();
  initMotores();
  initSensores();
  
  unsigned long ahora = millis();
  ultimoSensoresMs = ahora;
  ultimoTelemetriaMs = ahora;
}

// ============================================================
// LOOP PRINCIPAL
// ============================================================
void loop() {
  // Chequear recepción por serial continuamente sin bloquear
  chequearSerial();

  // Procesar comandos seriales si están disponibles
  if (stringComplete) {
    parsearComando(inputString);
    aplicarComandos();
    
    // Limpiar el string para la siguiente lectura
    inputString = "";
    stringComplete = false;
  }

  unsigned long ahora = millis();

  // Lazo de sensores a frecuencia fija
  if (ahora - ultimoSensoresMs >= SENSORES_INTERVALO_MS) {
    ultimoSensoresMs = ahora;
    actualizarSensores();
  }

  // Transmisión de telemetría a frecuencia fija
  if (ahora - ultimoTelemetriaMs >= TELEMETRIA_INTERVALO_MS) {
    ultimoTelemetriaMs = ahora;
    enviarTelemetria();
  }
}

// ============================================================
// COMUNICACIÓN SERIAL
// ============================================================
void initComunicacion() {
  Serial.begin(115200);
  inputString.reserve(50);
}

void chequearSerial() {
  while (Serial.available() && !stringComplete) {
    char inChar = (char)Serial.read();
    inputString += inChar;
    if (inChar == '\n') {
      stringComplete = true;
    }
  }
}

void parsearComando(String comando) {
  comando.trim();
  
  int idxV = comando.indexOf("V:");
  int idxA = comando.indexOf(";A:");
  
  if (idxV != -1 && idxA != -1) {
    String velStr = comando.substring(idxV + 2, idxA);
    String angStr = comando.substring(idxA + 3);
    
    int nuevaVel = velStr.toInt();
    int nuevoAng = angStr.toInt();
    
    if (nuevaVel == 0 && velStr != "0" && velStr != "0\r") return;
    if (nuevoAng == 0 && angStr != "0" && angStr != "0\r") return;
    
    velocidadActual = nuevaVel;
    anguloActual = nuevoAng;
  }
}

void enviarTelemetria() {
  Serial.print("T:Z:");
  Serial.print(mpu_z_acumulado, 1);
  Serial.print(";A:");
  Serial.print(anguloActual);
  Serial.print(";U:");
  Serial.print(distancia_trasera_cm);
  Serial.println(";");
}

// ============================================================
// CONTROL DE MOTORES
// ============================================================
void initMotores() {
  servoDireccion.attach(PIN_SERVO);
  servoDireccion.write(anguloActual);
  
  pinMode(PIN_RPWM, OUTPUT);
  pinMode(PIN_LPWM, OUTPUT);
  pinMode(PIN_R_EN, OUTPUT);
  pinMode(PIN_L_EN, OUTPUT);
  
  digitalWrite(PIN_R_EN, HIGH);
  digitalWrite(PIN_L_EN, HIGH);
  
  analogWrite(PIN_RPWM, 0);
  analogWrite(PIN_LPWM, 0);
}

void aplicarComandos() {
  int anguloSeguro = constrain(anguloActual, 0, 270);
  servoDireccion.write(anguloSeguro);
  
  if (velocidadActual == 0) {
    analogWrite(PIN_RPWM, 0);
    analogWrite(PIN_LPWM, 0);
  } else {
    int velPct = constrain(velocidadActual, -100, 100);
    int pwmOut = map(abs(velPct), 0, 100, 0, 255);
    bool reversa = velPct < 0;
    
    if (reversa) {
      analogWrite(PIN_RPWM, 0);
      analogWrite(PIN_LPWM, pwmOut);
    } else {
      analogWrite(PIN_RPWM, pwmOut);
      analogWrite(PIN_LPWM, 0);
    }
  }
}

// ============================================================
// SENSORES (MPU6050 + HC-SR04)
// ============================================================
void initSensores() {
  pinMode(PIN_TRIG_TRASERO, OUTPUT);
  pinMode(PIN_ECHO_TRASERO, INPUT);
  digitalWrite(PIN_TRIG_TRASERO, LOW);

  // Inicializar MPU6050 con timeout
  Wire.begin();
  Wire.setWireTimeout(1000, true);  // Timeout de 1ms
  
  Wire.beginTransmission(MPU_ADDR);
  Wire.write(0x6B);
  Wire.write(0);
  Wire.endTransmission(true);

  // Calibración de bias del eje Z (optimizada para no bloquear)
  long suma_z = 0;
  int muestras_validas = 0;
  for (int i = 0; i < GYRO_BIAS_MUESTRAS; i++) {
    Wire.beginTransmission(MPU_ADDR);
    Wire.write(0x47);
    Wire.endTransmission(false);
    Wire.requestFrom(MPU_ADDR, 2, true);
    if (Wire.available() == 2) {
      int16_t raw = Wire.read() << 8 | Wire.read();
      suma_z += raw;
      muestras_validas++;
    }
    delay(2);  // Reducido de 5ms a 2ms
  }
  if (muestras_validas > 0) {
    gyro_z_bias = (float)suma_z / (float)muestras_validas / 131.0f;
  }

  ultimaMedicionUs = micros();
}
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

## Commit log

2026-04-14 Add: estructura de proyecto y base del README
    [Rueda Terreneitor.STL]
2026-05-15 Estructura de directorios y readme competente
    [Rueda Terreneitor.STL]
2026-05-16 MVP intacto, migramos a estados finitos estados declarados, se puede pasar a desarrollo algoritmico pesado freno de emergencia (forzamos entrada al estado_fin.py) :v
2026-05-16 requirements.txt: incluye las librerias necesarias para el cerebro firmware_terreneitor.ino modularizado en distintos archivos cpp como en la planificacion compilado y ejecucion del codigo funcional,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
    [firmware_terreneitor.ino]
2026-05-20 añadimos algunos assets
    [Engranaje.STL, Rueda.STL]
2026-05-31 Cambios no funcionales solventado loop infinito en leer_distancia() agregado watchdog agregado leer_telemetria() rutas absolutas manejo de excepciones arduino.cerrar() modificado estado_fin() mejorad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
    [comms_arduino.py, firmware_terreneitor.ino, main.py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]
2026-06-06 POSIBLE MVP FALTAN TESTS (ajustar valores de reto) traduccion del readme al ingles (reglamento wro) mejor comentado de codigo multiples errores e inconsistencias resueltas deteccion de violacion de s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
    [comms_arduino.py, firmware_terreneitor.ino, main.py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]
2026-09-02 Modelo de Abrazadera 3D
    Abrazadera para la camara
    [Abrazadera WRO.SLDPRT]
2026-09-02 Modelo de Base para la Abrazadera
    Mastil donde va incorporada la camara
    [Base de la abrazadera WRO.SLDPRT]
2026-09-02 Modelo de la Base para el lidar 3D
    Base para el Lidar, conectado al servo motor
    [Base del Lidar WRO.SLDPRT]
2026-09-02 Modelo de la Base Principal 3D
    Base donde esta el Arduino Uno y el Raspberry Pi
    [Base.SLDPRT]
2026-09-02 Modelo de la Base para el Puente H 3D
    Base donde va a estar el Puente H y el sensor ultrasonico
    [Base 2 WRO.SLDPRT]
2026-09-04 Migracion gitlab a github
    [Abrazadera WRO.SLDPRT, Base 2 WRO.SLDPRT, Base de la abrazadera WRO.SLDPRT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]
2026-09-04 error de rutas systemd
2026-09-05 switch en lugar de pulsor
2026-09-05 Medicion de voltaje de las baterias
2026-09-05 refactorizacion de tests
2026-09-05 test completo y revision de capa de abstraccion
2026-09-05 correccion de andres
2026-09-05 firmware del terreneitor convertido en monolito para mejor mantenimiento (menos lineas)
2026-09-06 Prueba, capaz el mpu es el que evita el inicio de la carrera
2026-09-06 Reduccion masiva de logs (~90%) accede a logs de carrera con sudo journalctl -u wro-emergency.service --since "5 minutes ago" --no-pager
2026-09-06 adicion de camara y deteccion de pilares a script de emergencia
2026-09-06 limpieza de log del boton y solucion a boton de reinicio
2026-09-06 logs para debug mejorados
2026-09-07 DISCULPA POR EMOCIONARME CON EL DISEÑO MODULAR se prescindio de el exceso de la modularizacion para mejor legibilidad mejora de los scripts reorganizacion de la estructura de directorios este commit 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
2026-09-07 Correcciones, simplificaciones y refactorizaciones auto deteccion de sentido de giro autodeteccion de tipo de ronda images renaming bitacora tecnica updated
2026-09-07 para prueba
2026-09-07 buscando culpable de error puertos seriales
    [comms.py]
2026-09-08 dañamos el lidar, migramos a ultrasonico
2026-09-08 Botón siempre espera cambio de estado antes de iniciar
2026-09-08 Corregir lógica de botón con wait_for_press/wait_for_release
